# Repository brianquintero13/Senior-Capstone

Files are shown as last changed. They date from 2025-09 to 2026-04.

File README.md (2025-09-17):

# ShadeSync

## Project Description
ShadeSync is an ongoing project aimed at creating a smarter, more convenient way to manage window shades. The idea is to explore how automation and simple technology can improve daily routines, from better sleep at night to easier wake-ups in the morning. Our vision is to design a system that feels natural, reliable, and helpful — one that blends into everyday life and makes it just a little smoother.  

## Technology Stack
Drawing from our project design document, ShadeSync will use a combination of hardware and software to support automation, scheduling, and user interaction:  
- **Microcontroller:** ESP32 (for control, Wi-Fi, and Bluetooth connectivity)  
- **Control Logic:** Scripts to handle shade movement and scheduling routines  
- **Timekeeping:** RTC module or network time sync for reliable scheduling  
- **User Interface:** Android companion app for setup, scheduling, and manual control  
- **Input/Feedback:** Limit switches or encoders for shade positioning, with optional sensors for future features  

## Set Up and Run the Project Locally
This project is still under development, and setup instructions may change as it evolves. In general, the process will include:  
1. Cloning the repository from GitHub.  
2. Opening the project in a development environment.  
3. Uploading the code to the microcontroller or running the app on a device.  
4. Testing and adjusting features as new components are added.  

## Team Members
- Matthew Dauria  
- Brian Quintero  
- Jake Sussner  

**Roles:** Collaborative Development — all team members contribute equally to every part of the project.  

## Unique Contributions
- **Matthew Dauria** – Experience with artificial intelligence, especially in automation, non-playable characters for games, and data tracking.  
- **Brian Quintero** – Background in encrypted equipment, RF signals, PIR sensors, and remote-control systems.  
- **Jake Sussner** – Strong troubleshooting skills in both code and mechanics, with the ability to quickly identify and resolve errors.  

**Note:** While each member brings different skills to the table, we are teaching each other these areas of expertise throughout the project so everyone gains well-rounded knowledge.  

---

*This document will be updated as the project develops.*

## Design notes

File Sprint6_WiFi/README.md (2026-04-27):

## Sprint6 WiFi Firmware Builder Workflow

This firmware supports two profiles:

- `BUILD_PROFILE=1` builder-first mode (seed default WiFi credentials on first boot)
- `BUILD_PROFILE=0` customer mode (no seeded credentials)

### Generate flash-time builder config

From repo root:

```bash
export BUILDER_WIFI_SSID="YourBuilderNetwork"
export BUILDER_WIFI_PASSWORD="YourBuilderPassword"
export DEVICE_SETUP_CODE="YourSetupCode"
./Sprint6_WiFi/tools/generate_builder_config.sh
```

This creates `Sprint6_WiFi/builder_config.local.h` used at compile time.

### Builder handoff checklist

1. Generate builder config header.
2. Flash `Sprint6_WiFi.ino`.
3. Boot device and confirm serial log shows WiFi connected + IP.
4. Verify `GET /health` from builder network.
5. Verify open/close command path.
6. Hand off unit with setup code and reset-button recovery instructions.

### Customer recovery behavior

- Long-press reset button (4+ sec) enters setup AP mode.
- Setup AP has a limited window (default 10 min).
- Provisioning accepts authenticated `POST /wifi-config` only.

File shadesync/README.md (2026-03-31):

This is a [Next.js](https://nextjs.org) project bootstrapped with [`create-next-app`](https://github.com/vercel/next.js/tree/canary/packages/create-next-app).

## Getting Started

First, run the development server:

```bash
npm run dev
# or
yarn dev
# or
pnpm dev
# or
bun dev
```

Open [http://localhost:3000](http://localhost:3000) with your browser to see the result.

You can start editing the page by modifying `app/page.js`. The page auto-updates as you edit the file.

This project uses [`next/font`](https://nextjs.org/docs/app/building-your-application/optimizing/fonts) to automatically optimize and load [Geist](https://vercel.com/font), a new font family for Vercel.

## Arduino Manual Control Wiring

Manual `Open` / `Close` buttons now send commands through the backend to the motor controller over USB serial, and both manual buttons are disabled while the motor is moving.

Set these environment variables in `.env.local`:

```bash
SERIAL_PORT_PATH=/dev/tty.usbserial-0001
SERIAL_BAUD_RATE=115200
MOTOR_COMMAND_TIMEOUT_MS=25000
```

Endpoints used:

- `POST /api/device-command` with `{ "action": "open" }` or `{ "action": "close" }`
- `GET /api/device-status` as Server-Sent Events (`status` events)

Arduino firmware is expected to:

- Accept `OPEN` / `CLOSE` commands via serial (newline-terminated)
- Emit `OPEN complete` / `CLOSE complete` when movement finishes

## Learn More

To learn more about Next.js, take a look at the following resources:

- [Next.js Documentation](https://nextjs.org/docs) - learn about Next.js features and API.
- [Learn Next.js](https://nextjs.org/learn) - an interactive Next.js tutorial.

You can check out [the Next.js GitHub repository](https://github.com/vercel/next.js) - your feedback and contributions are welcome!

## Deploy on Vercel

The easiest way to deploy your Next.js app is to use the [Vercel Platform](https://vercel.com/new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) from the creators of Next.js.

Check out our [Next.js deployment documentation](https://nextjs.org/docs/app/building-your-application/deploying) for more details.

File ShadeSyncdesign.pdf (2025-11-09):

Project Title: ShadeSync

Team Name: The Lightbenders

Team Members:

- Matthew Dauria – Collaborative Development Role
- Jake Sussner – Collaborative Development Role
- Brian Quintero – Collaborative Development Role

(Our team works together across hardware, software, and testing. Each member brings unique strengths but all roles overlap.)

GitHub Repository URL: https://github.com/brianquintero13/Senior-Capstone

Trello Board URL: https://trello.com/b/8fFUBatY/shadesync
Diagrams

Create the required diagrams to help you visualize and communicate the design of your system. Each diagram should be in .png or .jpg format, properly named (e.g., context.png,
dataflow.png), and included in a ZIP file for submission.

### 1. Context diagram

Create a Context Diagram that shows the entire system and its interactions with external entities (users, is clear and shows all important system interactions.

### 2. Data flow diagram

Create a Data Flow Diagram (DFD) showing the flow of data within your system. Choose one of the data and expand it to show how the input becomes output. The diagram should have
sufficient detail and clarity.

### 3. Use case diagram

Create a Use Case Diagram for one of your system’s features.
Include at least five use cases that represent different user interactions with the
system. Clearly define the actors and the use cases that describe how users interact with your system.

### 4. Sequence diagram

Create a Sequence Diagram for one of the use cases from your
Use Case Diagram. This diagram should show the full interactions required for the
selected use case, detailing the messages exchanged between objects

### 5. Class diagram

Create a Class Diagram that shows the classes and methods used in your Sequence Diagram, as well a your system needs. Ensure there are at least four user-defined types represented,
showing the structure of your system’s objects.

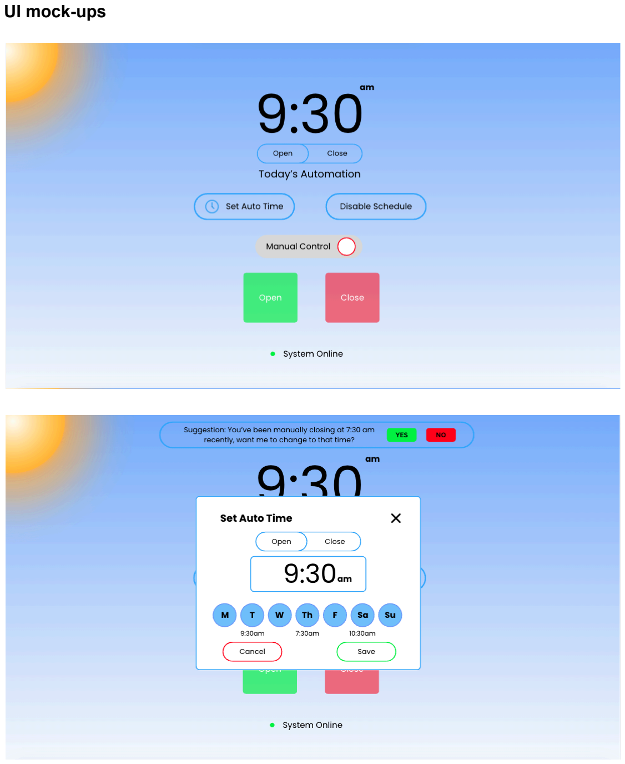
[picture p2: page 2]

UI mock-ups

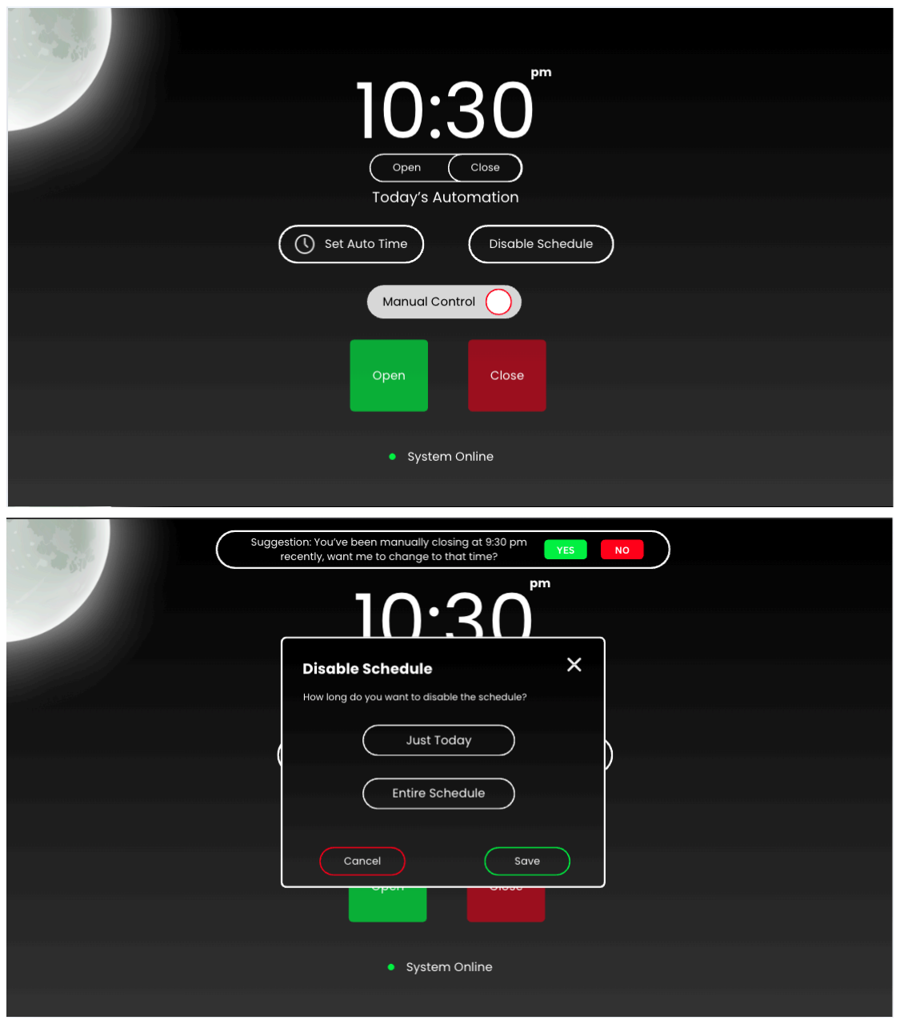
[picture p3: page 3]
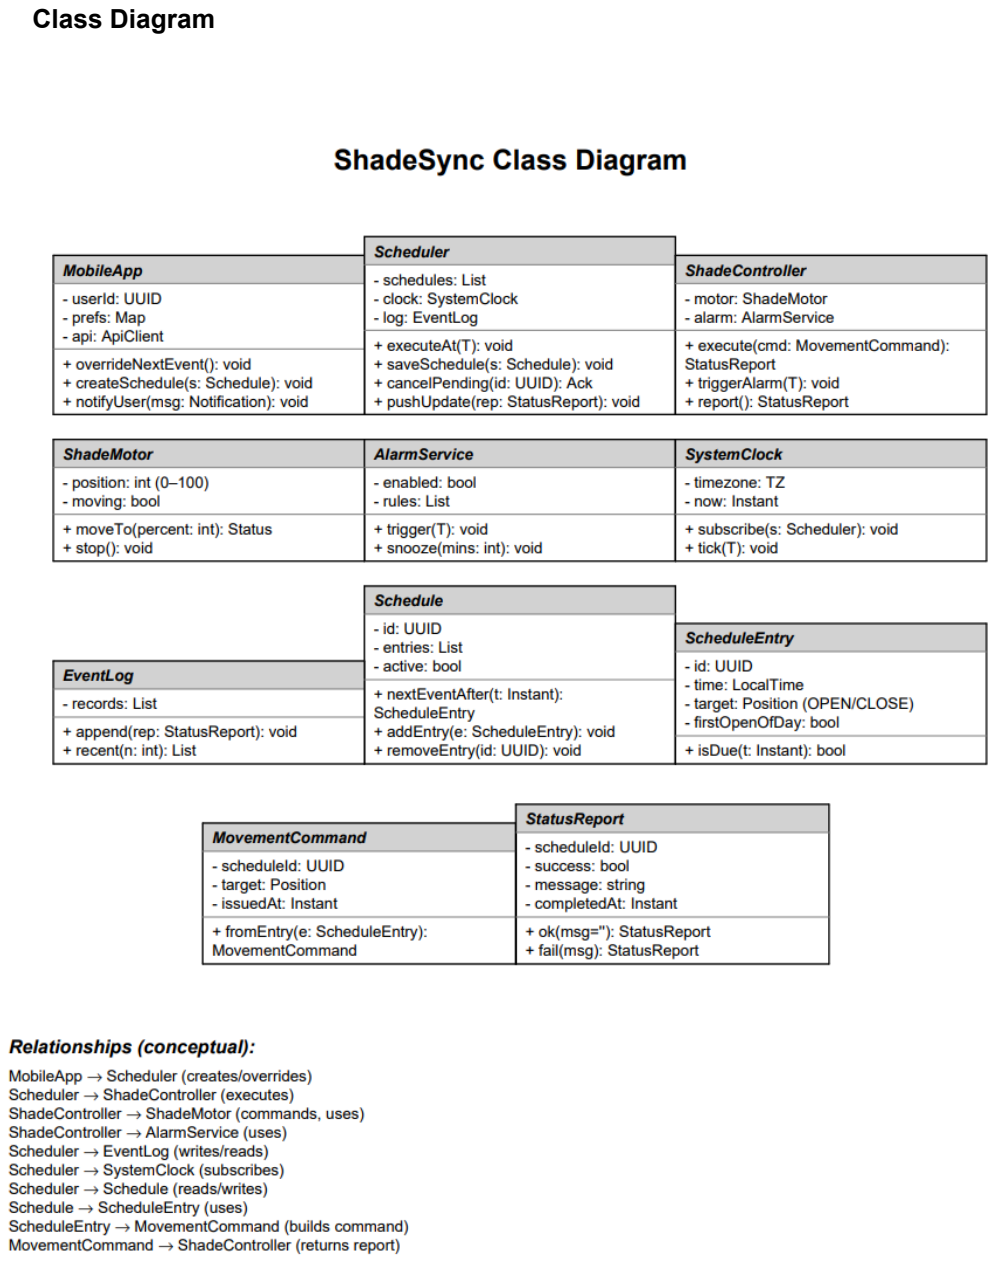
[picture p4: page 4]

Class Diagram

Sequence Diagram

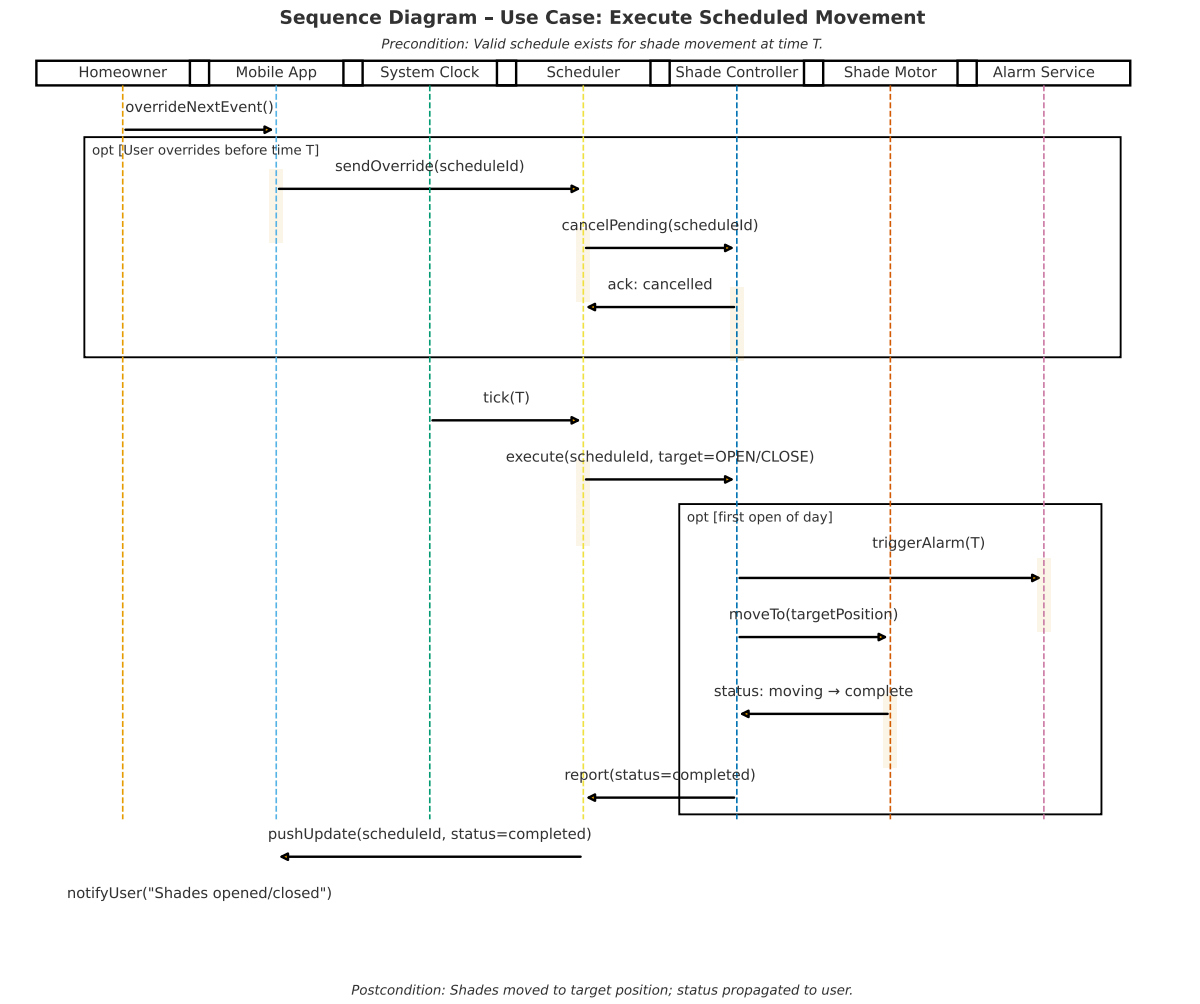
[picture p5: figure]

Use Case Diagram

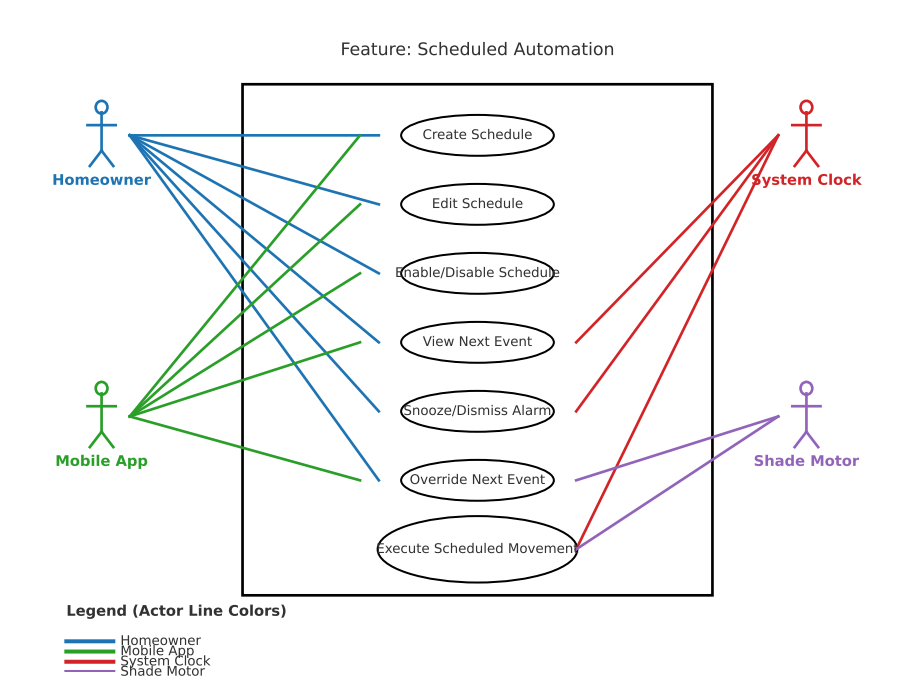
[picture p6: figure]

Data Flow Diagram

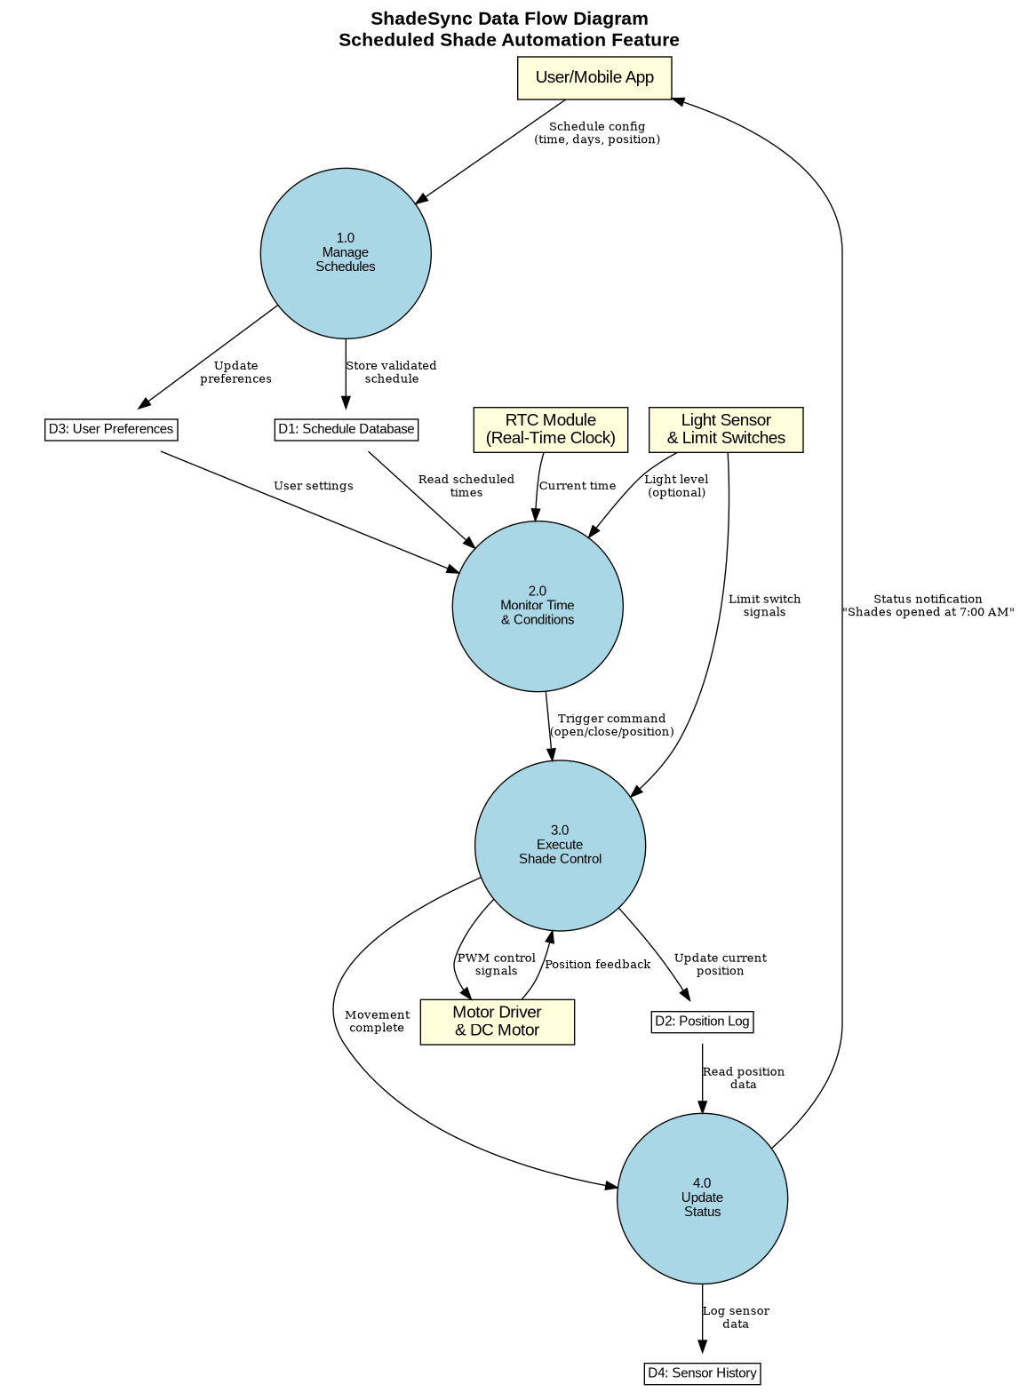
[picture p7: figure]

Context Diagram

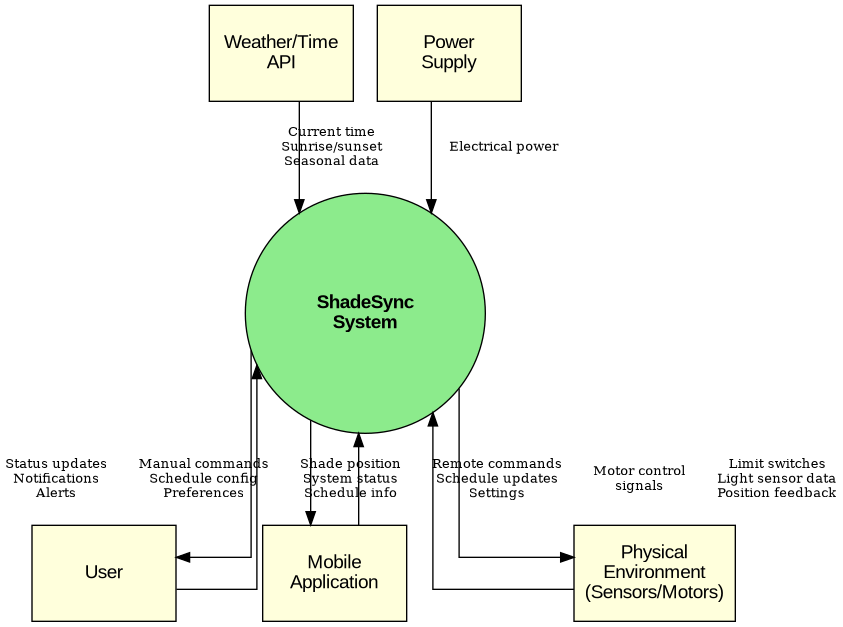
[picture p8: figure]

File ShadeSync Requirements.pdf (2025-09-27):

Project Title: ShadeSync

Team Name: The Lightbenders

Team Members:

- Matthew Dauria – Collaborative Development Role
- Jake Sussner – Collaborative Development Role
- Brian Quintero – Collaborative Development Role

(Our team works together across hardware, software, and testing. Each member brings unique strengths but all roles overlap.)

GitHub Repository URL: https://github.com/brianquintero13/Senior-Capstone

Trello Board URL: https://trello.com/b/8fFUBatY/shadesync

Brief Summary

ShadeSync is a smart motorized window shade system designed to improve comfort, efficiency, and daily routines. It provides scheduled automation, manual override through physical controls or a remote, and mobile connectivity for convenience. Beyond light control, the system can help regulate indoor temperature by lowering shades when no one is home, reducing energy use. Planned AI features will further adapt schedules to user habits and seasonal changes, creating a reliable and customizable solution for modern living.

Main Features

1. Scheduled Shade Automation
Shades open and close at set times, supporting healthier routines and improving energy efficiency by reducing heat gain or loss when the home is unoccupied.
2. Mobile Application Integration
A companion app allows users to remotely control shades, manage schedules, and customize preferences for greater convenience and flexibility.
3. Adaptive Intelligence (Planned)
Future integration of machine learning will analyze user behavior and seasonal light patterns to recommend optimized schedules, creating a more adaptive system.

Sprint Outline

Sprint 1: Focus on foundational tasks by defining the hardware requirements, selecting components, mounting the shades, and enabling manual control with safety stops.

Sprint 2: Assemble and debug the prototype, implement a reliable timekeeping system, and introduce scheduled automation for morning opening and night closing, with the alarm feature as a secondary goal.

Sprint 3: Finalize the system by connecting the prototype to mounted shades, integrating mobile app control, and adding in-app schedule management, followed by testing for consistency and stability.

MOSCOW Summary:

- Must Have: Hardware setup, safety measures, automated scheduling
- Should Have: Mobile app control, alarm function
- Could Have: AI suggestions, customization options, environmental sensor
- Won’t Have: Alternative shade types, full cross-platform app deployment

Extra Work (If Time Allows)

- Cross-Platform App: Expand beyond Android to develop a full iOS/Android mobile application.
- Alternative Shade Types: Extend functionality to support shades that open left-to-right as well as top-down.
- AI Behavior Suggestions: Implement behavior tracking to recommend optimized schedules based on user habits and seasonal changes.
- Accessibility & Customization: Add optional features such as LED indicators, customizable alarm sounds, and mobile notifications.
- Sunlight Auto-Adjust: Integrate a light sensor to dynamically adjust shades according to user-defined brightness preferences.

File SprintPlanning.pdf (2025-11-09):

# ShadeSync

## The Lightbenders

Brian Quintero, Matthew Dauria, Jake Sussner

GitHub repository: https://github.com/brianquintero13/Senior-Capstone

Trello board: https://trello.com/b/8fFUBatY/shadesync

## Sprint 1

Spring Goal: Defining the hardware requirements, selecting components, mounting the shades, and enabling manual control with safety stops.

Tasks:
1. Define ShadeSync’s hardware and requirements, to select the correct components before building.
a. Effort: ~1-2 hours
b. Assigned Team Member: Matthew Dauria
2. Properly hang up shades, so the system can open and close them.
a. Effort: ~1 hour
b. Assigned Team Member: Brian Quintero
c. Dependency: Task 1 needs to be completed
3. Open and close the shades manually, so I can control the amount of light in my room.
a. Effort: ~1 hour
b. Assigned Team Member: Jake Sussner
c. Dependency: Task 2 needs to be completed

## Sprint 2

Spring Goal: Assemble and debug the prototype, implement a reliable timekeeping system, and introduce scheduled automation for morning opening and night closing, with the alarm feature as a secondary goal.

Tasks:
1. Build a working prototype, so we can test hardware, software, and communication together.
a. Effort: ~1-3 days
b. Assigned Team Member(s): All
2. Make shades automatically open/close, so my routine happens without manual effort.

a. Effort: ~3-5 days
b. Assigned Team Member(s): All
c. Dependency: Task 1 needs to be completed with the mobilized frame in hand
3. Stop shades automatically so they don’t get damaged.
a. Effort: ~3 hours
b. Assigned Team Member: All Members
c. Dependency: Task 2 needs to be completed

## Sprint 3

Sprint Goal: Deploy ShadeSync on the mounted window frame and demonstrate end-to-end control from a phone (manual + scheduled), while enabling basic behavior-based recommendations that adapt schedules over time.

## Trello board

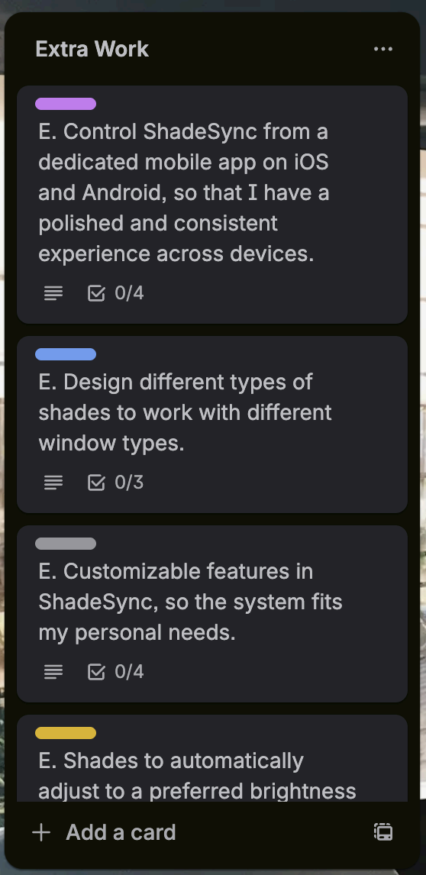
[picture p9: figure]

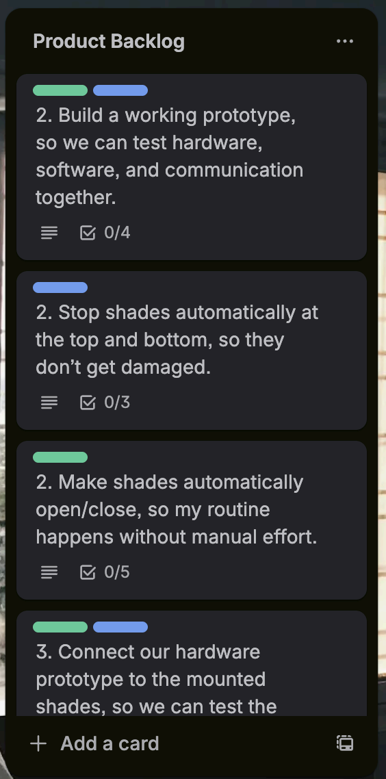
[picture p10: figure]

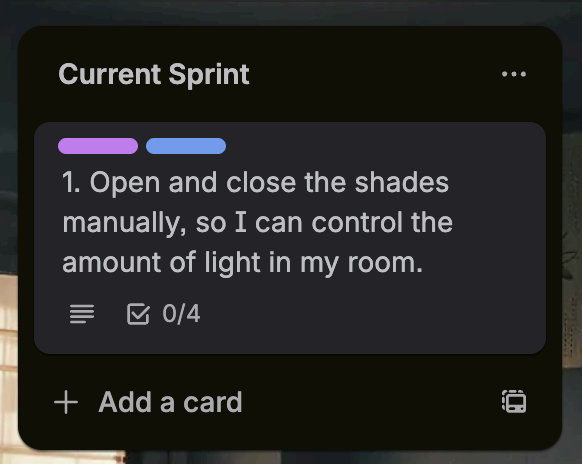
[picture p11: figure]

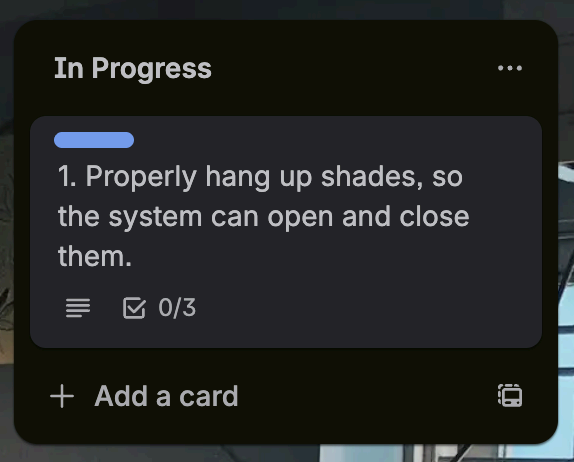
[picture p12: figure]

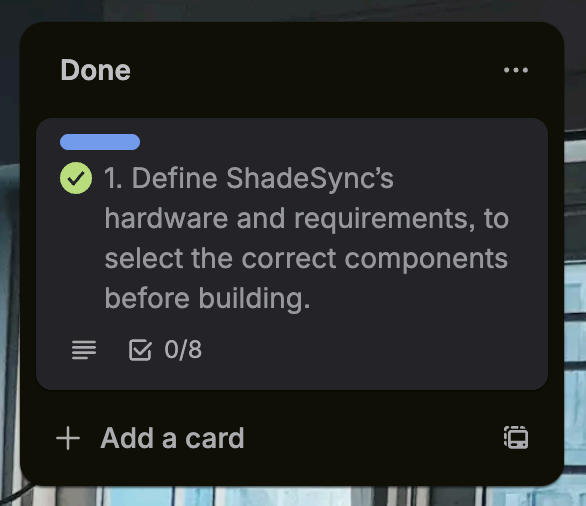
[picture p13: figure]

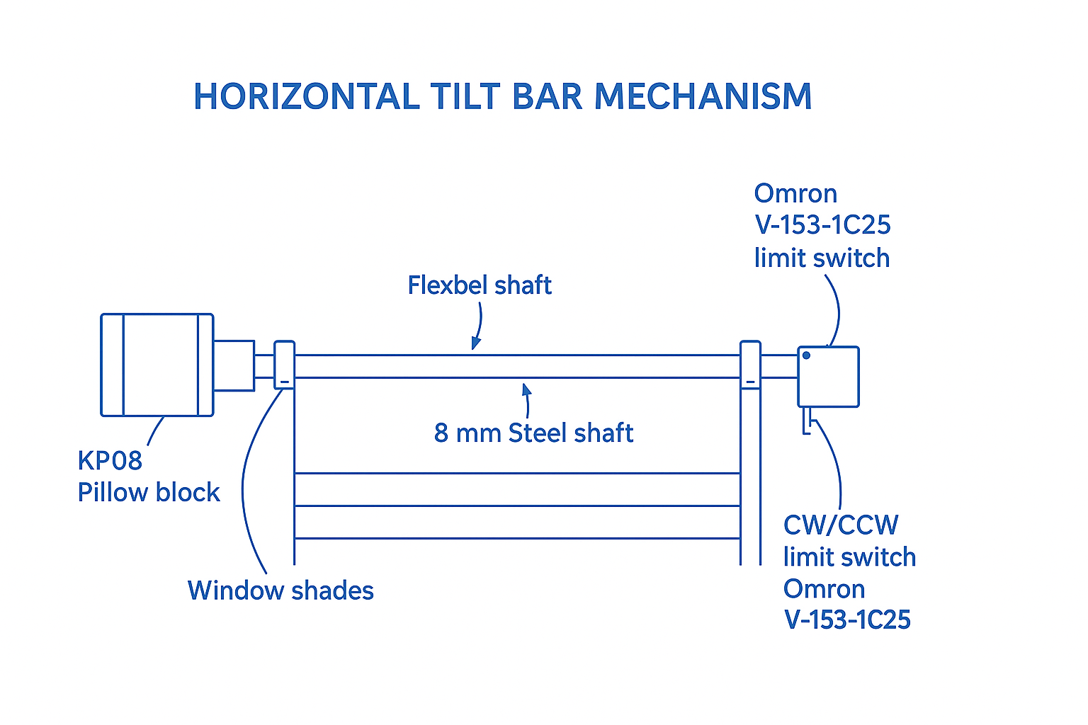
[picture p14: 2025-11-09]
Shade Design Blueprint.png

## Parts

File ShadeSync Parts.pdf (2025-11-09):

# ShadeSync — Budget-Fit Bill of Materials (BOM)

Totals are ballpark and vary slightly by seller.

### Totals Summary

Section | Subtotal
Shared base (reuse for all) | $187.01
Add vertical (5 rollers) | $200.10
Add horizontal tilt | $62.29
Shared + Vertical | $387.11
Shared + Horizontal | $249.30
Shared + Vertical + Horizontal | $449.40

### Shared base (buy once, reused for both builds)

Item | Qty | Unit | Ext. | Notes / Purpose
BIGTREETECH SKR 1.4 (control board) (https://www.zyltech.com/electronics-motors-more/official-bigtree-tech-skr/) (Zyltech) | 1 | $24.95 | $24.95 | Main controller for up to 5 steppers; STEP/DIR outputs, endstops, 24 V input.
TMC2209 stepper drivers (5-pack) (https://wuxn3d.com/products/bigtreetech-tmc2209-stepper-driver) (Wuxn3D) | 1 | $29.99 | $29.99 | Silent, reliable drivers; one per motor axis (x5).
ESP32 DevKitC (Wi-Fi/BLE) (https://www.digikey.com/en/products/detail/espressif-systems/ESP32-DEVKITC-32E/12091810) (Digi-Key) | 1 | $10.00 | $10.00 | Mobile app + weather logic; sends commands to

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
). Mean Well LRS-200-24 (24 V PSU) (Mouser) | 1 | $23.30 | $23.30 | Clean 24 V power for motors and drivers. Pololu D36V28F5 (5 V buck, 3.2 A) (Pololu) | 1 | $21.95 | $21.95 | Steps 24 V down to 5 V fo

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
s. 22 mm latching Emergency Stop (1NO/1NC) (Amazon) | 1 | $13.99 | $13.99 | Safety cu

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
U. WAGO 221-413 Lever Nuts (3-conductor, 50-pack) (Amazon) | 1 | $19.84 | $19.84 | Safe, too

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
s. 18 AWG silicone wire kit (multi-color) (Amazon) | 1 | $18.00 | $18.00 | Power wi

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
d. JST-XH connector kit / pre-crimp leads (Amazon) | 1 | $9.99 | $9.99 | Connect motors, endstops, an

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
y. Hammond 1591 enclosure (size to fit) (Amazon) | 1 | $15.00 | $15.00 | Mount

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
fe. Section subtotal: $187.01

### Build A — 5 independent vertical rollers (add to shared base)

Item (clickable) Qty | Unit | Ext. | Notes / Purpose

NEMA-17
stepper
17HS19-1684S
1 (45 N·cm) (https://www.omc-stepperonline.com/nema-17-bipolar-1-8deg-45ncm-64oz-in-1-68a-2-8v-42x42x48mm-4-wires-17hs19-1684s1)
(StepperOnline)
5 | $10.44 | $52.20 | One motor per roller lane.

6061-T6
aluminum tube,
1" OD x 0.058"
wall (36") (https://www.onlinemetals.com/en/buy/aluminum/1-od-x-0-058-wall-x-0-884-id-aluminum-round-tube-6061-t6-drawn/pid/4342)
(OnlineMetals)
2 | $28.95 | $57.90 | Cut into five roller cores; deburr ends.

608ZZ bearings
(10-pack) (https://www.amazon.com/Bearings-Double-Shielded-Miniature-Skateboard/dp/B07H83VV6B)
(Amazon)
1 | $10.00 | $10.00 | Two bearings per roller for smooth support.

Flexible shaft
couplers 5 mm
-> 5 mm
(5-pack) (https://www.amazon.com/Saiper-Couplings-Connector-Compatible-Accessories/dp/B07M5Q7HTV)
(Amazon)
1 | $15.00 | $15.00 | Couple motor shafts to roller hub inserts.

NEMA-17
L-brackets
(5-pack) (https://www.amazon.com/5pcs-Mounting-Bracket-Mount-Stepper-Motor/dp/B07YY6WH1D)
(Amazon)
1 | $18.00 | $18.00 | Rigid mounting of motors to the wooden frame.

Omron
V-153-1C25
long-lever limit
switch (https://www.mouser.com/ProductDetail/Omron-Electronics/V-153-1C25?qs=WOBxwZpV8jWr%252BiSFeM5Nxw%3D%3D)
(Mouser)
10 | $4.70 | $47.00 | Top/bottom endstops for each lane (2 per roller).

Section subtotal: $200.10

### Build B — Horizontal tilt bar (add to shared base)

Item (clickable) Qty | Unit | Ext. | Notes / Purpose

NEMA-17
stepper
17HS19-1684S
1 (45 N·cm) (https://www.omc-stepperonline.com/nema-17-bipolar-1-8deg-45ncm-64oz-in-1-68a-2-8v-42x42x48mm-4-wires-17hs19-1684s1)
(StepperOnline)
1 | $10.44 | $10.44 | Drives the common tilt shaft.

8 mm linear
steel shaft
(~400 mm) (https://www.amazon.com/uxcell-Linear-Hardened-Printer-Machine/dp/B0D2BJ15MY)
(Amazon)
1 | $20.49 | $20.49 | Common tilt bar across slats.

KP08 pillow
blocks (8 mm,
pair) (https://www.amazon.com/uxcell-Mounted-Pillow-Insert-Bearing/dp/B073LDH4L7) (Amazon)
1 | $12.00 | $12.00 | Shaft supports at ends; keeps alignment.

Flexible shaft
coupler 5 mm
-> 8 mm (https://www.amazon.com/Befenybay-Flexible-Coupling-Diameter-Aluminum/dp/B0843TFVWZ)
(Amazon)
1 | $8.00 | $8.00 | Couple motor (5 mm) to 8 mm tilt shaft.

Omron
V-153-1C25
long-lever limit
switch (https://www.mouser.com/ProductDetail/Omron-Electronics/V-153-1C25?qs=WOBxwZpV8jWr%252BiSFeM5Nxw%3D%3D)
(Mouser)
2 | $5.68 | $11.36 | CW/CCW tilt endstops (2 total).

Section subtotal: $62.29

### Connection Overview (how the parts are used)

- AC mains -> Emergency-stop (series on hot) -> Mean Well LRS-200-24 PSU -> 24 V to SKR and TMC2209 drivers.
- PSU -> Pololu 5 V buck -> ESP32 5 V and any sensors.
- ESP32 communicates with SKR (UART or STEP/DIR GPIO) and hosts the mobile/HTTP API + weather logic.
- Vertical build: each lane uses 1x NEMA-17, a 5->5 mm coupler to a 1" aluminum roller, with 608ZZ bearings and two limit switches (top/bottom).
- Horizontal build: one NEMA-17 -> 5->8 mm coupler -> 8 mm shaft on KP08 pillow blocks; two limit switches (CW/CCW).

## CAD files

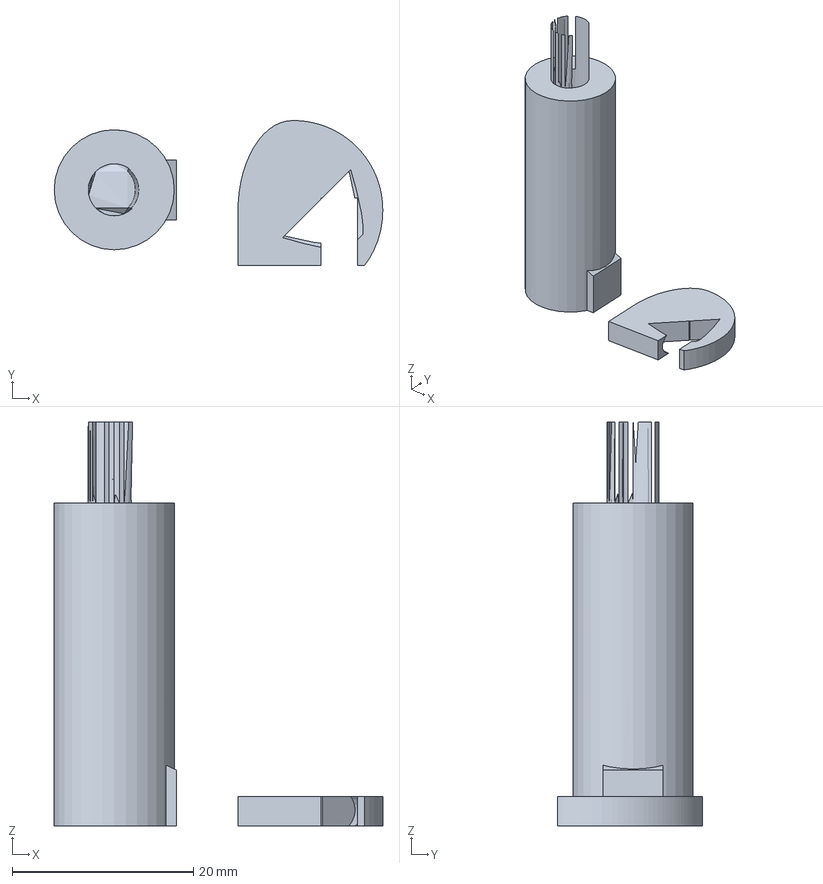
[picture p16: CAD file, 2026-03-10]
blindhook.3mf
36.3 x 16.0 x 44.6 mm

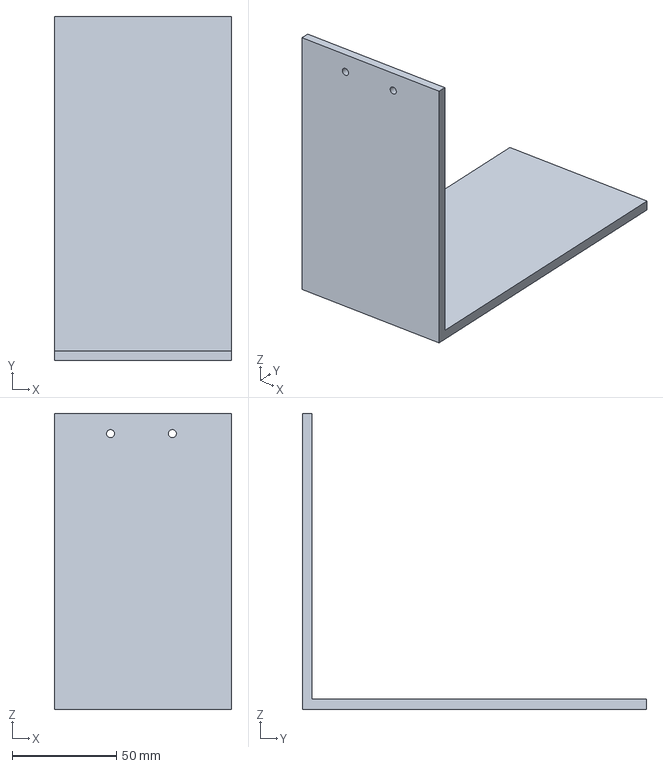
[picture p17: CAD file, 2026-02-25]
MotorClamp.3mf
85.0 x 165.0 x 142.0 mm

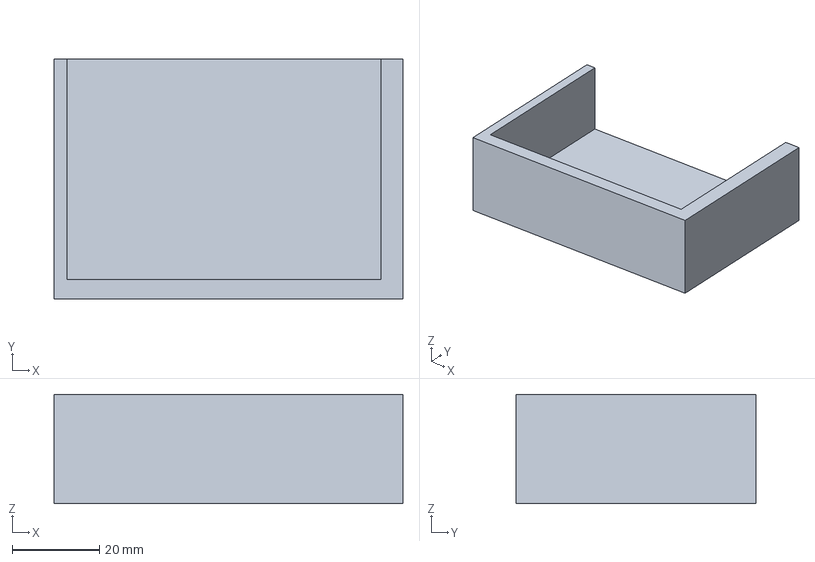
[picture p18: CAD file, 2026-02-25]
MotorHolder.3mf
80.0 x 55.0 x 25.0 mm

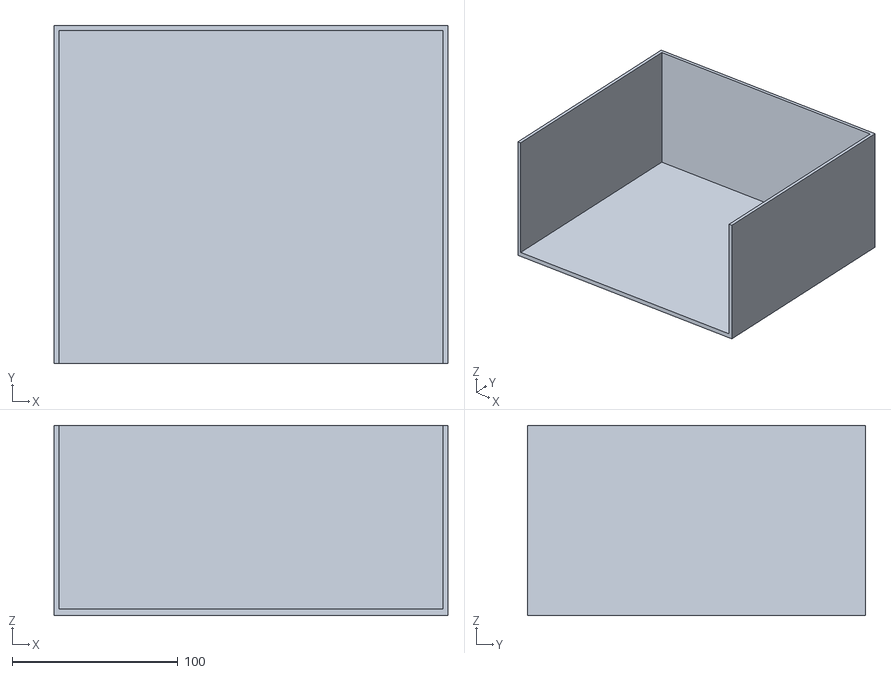
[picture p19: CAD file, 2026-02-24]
EndBoxPiece.stl
238.0 x 204.0 x 115.0

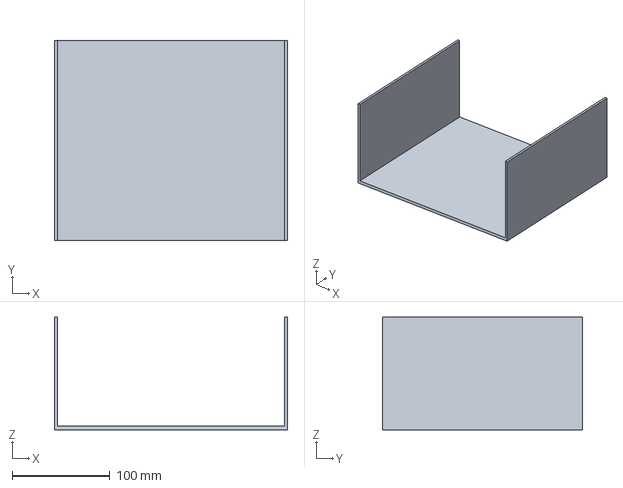
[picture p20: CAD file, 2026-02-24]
MiddleBoxPiece.3mf
238.0 x 204.0 x 115.0 mm

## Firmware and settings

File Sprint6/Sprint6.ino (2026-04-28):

#include <WiFi.h>
#include <WiFiServer.h>
#include <EEPROM.h>

// Pin definitions
#define STEP_PIN 12
#define DIR_PIN 14
#define ENABLE_PIN 13

// EEPROM settings
#define EEPROM_SIZE 512
#define SSID_ADDR 0
#define PASSWORD_ADDR 100

// Motor settings
const int stepsPerRevolution = 1600;
const int rotations = 5;
const int totalSteps = stepsPerRevolution * rotations;

// Command settings
const int OPEN_DIR = HIGH;
const int CLOSE_DIR = LOW;

// WiFi settings
char ssid[50] = "";
char password[50] = "";

WiFiServer server(80);

// Motor state
bool isMoving = false;

// Function to save WiFi credentials to EEPROM
void saveWiFiCredentials(const char* newSSID, const char* newPassword) {
  EEPROM.begin(EEPROM_SIZE);
  
  // Save SSID
  for (int i = 0; i < 50; i++) {
    EEPROM.write(SSID_ADDR + i, newSSID[i]);
    if (newSSID[i] == '\0') break;
  }
  
  // Save password
  for (int i = 0; i < 50; i++) {
    EEPROM.write(PASSWORD_ADDR + i, newPassword[i]);
    if (newPassword[i] == '\0') break;
  }
  
  EEPROM.commit();
  EEPROM.end();
  Serial.println("WiFi credentials saved to EEPROM");
}

// Function to load WiFi credentials from EEPROM
void loadWiFiCredentials() {
  EEPROM.begin(EEPROM_SIZE);
  
  // Load SSID
  for (int i = 0; i < 50; i++) {
    ssid[i] = EEPROM.read(SSID_ADDR + i);
    if (ssid[i] == '\0') break;
  }
  
  // Load password
  for (int i = 0; i < 50; i++) {
    password[i] = EEPROM.read(PASSWORD_ADDR + i);
    if (password[i] == '\0') break;
  }
  
  EEPROM.end();
  Serial.print("Loaded SSID: ");
  Serial.println(ssid);
  Serial.println("Password loaded (hidden)");
}

// Function to check if credentials exist in EEPROM
bool hasStoredCredentials() {
  EEPROM.begin(EEPROM_SIZE);
  char firstChar = EEPROM.read(SSID_ADDR);
  EEPROM.end();
  return (firstChar != 0 && firstChar != 255);
}

// Function to clear WiFi credentials from EEPROM
void clearWiFiCredentials() {
  EEPROM.begin(EEPROM_SIZE);
  
  // Clear SSID
  for (int i = 0; i < 50; i++) {
    EEPROM.write(SSID_ADDR + i, 0);
  }
  
  // Clear password
  for (int i = 0; i < 50; i++) {
    EEPROM.write(PASSWORD_ADDR + i, 0);
  }
  
  EEPROM.commit();
  EEPROM.end();
  Serial.println("WiFi credentials cleared from EEPROM");
}

// Function to decode URL-encoded strings
String urlDecode(String input) {
  String output = "";
  for (int i = 0; i < input.length(); i++) {
    char c = input.charAt(i);
    if (c == '+') {
      output += ' ';
    } else if (c == '%') {
      if (i + 2 < input.length()) {
        String hex = input.substring(i + 1, i + 3);
        char decoded = (char)strtol(hex.c_str(), NULL, 16);
        output += decoded;
        i += 2;
      }
    } else {
      output += c;
    }
  }
  return output;
}

void rotateMotor(int direction) {
  isMoving = true;
  digitalWrite(DIR_PIN, direction);

  for (int i = 0; i < totalSteps; i++) {
    digitalWrite(STEP_PIN, HIGH);
    delayMicroseconds(800);
    digitalWrite(STEP_PIN, LOW);
    delayMicroseconds(800);
  }
  isMoving = false;
}

void setup() {
  Serial.begin(115200);
  
  // Add delay to allow Serial Monitor to connect
  delay(2000);
  
  Serial.println("=================================");
  Serial.println("ESP32 Starting Up...");
  Serial.println("=================================");
  
  // Check if BOOT button is pressed to clear EEPROM
  pinMode(0, INPUT_PULLUP);
  delay(100);
  if (digitalRead(0) == LOW) {
    Serial.println("BOOT button pressed - clearing WiFi credentials from EEPROM");
    clearWiFiCredentials();
    Serial.println("EEPROM cleared. Release BOOT button and restart to configure new WiFi.");
    while (digitalRead(0) == LOW) {
      delay(100);
    }
    ESP.restart();
  }
  
  // Motor pins
  pinMode(STEP_PIN, OUTPUT);
  pinMode(DIR_PIN, OUTPUT);
  pinMode(ENABLE_PIN, OUTPUT);
  digitalWrite(ENABLE_PIN, LOW); // Enable motor driver
  
  Serial.println("Motor pins configured");

  // Load WiFi credentials from EEPROM
  if (hasStoredCredentials()) {
    Serial.println("Found stored WiFi credentials");
    loadWiFiCredentials();
    
    // Validate SSID is not empty
    if (strlen(ssid) == 0 || ssid[0] == 0 || ssid[0] == 255) {
      Serial.println("Invalid SSID in EEPROM, clearing and starting AP mode");
      clearWiFiCredentials();
      WiFi.mode(WIFI_AP);
      WiFi.softAP("ShadeSync-Setup", "setup1234");
      Serial.println("AP mode started");
      Serial.print("AP IP: ");
      Serial.println(WiFi.softAPIP());
      server.begin();
      Serial.println("Server started in AP mode");
      Serial.println("Connect to 'ShadeSync-Setup' WiFi and configure your network");
      Serial.println("=================================");
      return;
    }
  } else {
    Serial.println("No stored WiFi credentials found");
    Serial.println("Please configure WiFi via the web interface");
    // Start in AP mode for initial configuration
    WiFi.mode(WIFI_AP);
    WiFi.softAP("ShadeSync-Setup", "setup1234");
    Serial.println("AP mode started");
    Serial.print("AP IP: ");
    Serial.println(WiFi.softAPIP());
    server.begin();
    Serial.println("Server started in AP mode");
    Serial.println("Connect to 'ShadeSync-Setup' WiFi and configure your network");
    Serial.println("=================================");
    return; // Skip WiFi connection in STA mode
  }

  // WiFi setup
  Serial.println("Connecting to WiFi...");
  Serial.print("SSID: ");
  Serial.println(ssid);
  
  // Set WiFi mode
  WiFi.mode(WIFI_STA);
  WiFi.disconnect();
  delay(100);
  
  // Try multiple connection attempts
  int attempts = 0;
  bool connected = false;
  
  while (!connected && attempts < 40) {
    Serial.print("Attempt ");
    Serial.print(attempts + 1);
    Serial.print(" - ");
    
    WiFi.begin(ssid, password);
    
    // Wait for connection with timeout
    int connectionAttempts = 0;
    while (WiFi.status() != WL_CONNECTED && connectionAttempts < 20) {
      delay(500);
      connectionAttempts++;
      
      if (WiFi.status() == WL_CONNECTED) {
        connected = true;
        break;
      }
    }
    
    if (connected) {
      break;
    }
    
    Serial.print("Status: ");
    Serial.println(WiFi.status());
    
    // Reset and try different approach
    WiFi.disconnect();
    delay(1000);
    
    // Every 10 attempts, try with WiFi power cycle
    if (attempts % 10 == 9) {
      Serial.println("Power cycling WiFi...");
      WiFi.mode(WIFI_OFF);
      delay(1000);
      WiFi.mode(WIFI_STA);
      delay(500);
    }
    
    attempts++;
  }
  
  if (WiFi.status() == WL_CONNECTED) {
    Serial.println("WiFi connected!");
    Serial.print("IP address: ");
    Serial.println(WiFi.localIP());
    
    server.begin();
    Serial.println("Server started");
    Serial.println("=================================");
  } else {
    Serial.println("Failed to connect to WiFi after all attempts");
    Serial.println("Clearing credentials and starting AP mode for reconfiguration");
    clearWiFiCredentials();
    
    // Start in AP mode for reconfiguration
    WiFi.mode(WIFI_AP);
    WiFi.softAP("ShadeSync-Setup", "setup1234");
    Serial.println("AP mode started");
    Serial.print("AP IP: ");
    Serial.println(WiFi.softAPIP());
    server.begin();
    Serial.println("Server started in AP mode");
    Serial.println("Connect to 'ShadeSync-Setup' WiFi and configure your network");
    Serial.println("=================================");
  }
}

void loop() {
  // Only check WiFi connection if we're in STA mode (not AP mode)
  if (WiFi.getMode() == WIFI_STA && WiFi.status() != WL_CONNECTED) {
    Serial.println("WiFi disconnected, attempting to reconnect...");
    WiFi.disconnect();
    delay(1000);
    WiFi.begin(ssid, password);
    
    int reconnectAttempts = 0;
    while (WiFi.status() != WL_CONNECTED && reconnectAttempts < 20) {
      delay(500);
      Serial.print(".");
      reconnectAttempts++;
    }
    
    if (WiFi.status() == WL_CONNECTED) {
      Serial.println("\nWiFi reconnected!");
      Serial.print("IP address: ");
      Serial.println(WiFi.localIP());
      server.begin();
      Serial.println("Server restarted");
    } else {
      Serial.println("\nFailed to reconnect to WiFi");
    }
  }
  
  WiFiClient client = server.available();
  
  if (client) {
    Serial.println("Client connected");
    String currentLine = "";
    String request = "";
    
    // Read the request
    while (client.connected()) {
      if (client.available()) {
        char c = client.read();
        request += c;
        
        if (c == '\n') {
          if (currentLine.length() == 0) {
            // End of headers, send response
            break;
          } else {
            currentLine = "";
          }
        } else if (c != '\r') {
          currentLine += c;
        }
      }
    }
    
    // Process the request
    Serial.print("Request: ");
    Serial.println(request);
    
    // Send HTTP response
    client.println("HTTP/1.1 200 OK");
    client.println("Content-Type: text/plain");
    client.println("Access-Control-Allow-Origin: *");
    client.println("Access-Control-Allow-Methods: GET, POST, OPTIONS");
    client.println("Access-Control-Allow-Headers: Content-Type");
    client.println("Connection: close");
    client.println();
    
    // Check for commands in the request
    if (request.indexOf("GET / ") != -1 || request.indexOf("GET /index.html") != -1) {
      // Root path - return simple response
      client.print("ShadeSync ESP32 is running in AP mode. Please configure WiFi via your website.");
    } else if (request.indexOf("GET /OPEN") != -1) {
      if (!isMoving) {
        Serial.println("Received OPEN command");
        rotateMotor(OPEN_DIR);
        client.print("OPEN complete");
      } else {
        client.print("BUSY");
      }
    } else if (request.indexOf("GET /CLOSE") != -1) {
      if (!isMoving) {
        Serial.println("Received CLOSE command");
        rotateMotor(CLOSE_DIR);
        client.print("CLOSE complete");
      } else {
        client.print("BUSY");
      }
    } else if (request.indexOf("GET /WIFI_CONFIG") != -1) {
      // Parse SSID and password from request
      int ssidStart = request.indexOf("ssid=") + 5;
      int ssidEnd = request.indexOf("&", ssidStart);
      if (ssidEnd == -1) ssidEnd = request.indexOf(" ", ssidStart);
      
      int passwordStart = request.indexOf("password=") + 9;
      int passwordEnd = request.indexOf(" ", passwordStart);
      if (passwordEnd == -1) passwordEnd = request.length();
      
      String newSSID = request.substring(ssidStart, ssidEnd);
      String newPassword = request.substring(passwordStart, passwordEnd);
      
      // Decode URL encoding (handles %20 for spaces, etc.)
      newSSID = urlDecode(newSSID);
      newPassword = urlDecode(newPassword);
      
      Serial.println("Received WiFi credentials:");
      Serial.print("SSID: ");
      Serial.println(newSSID);
      
      // Save to EEPROM
      saveWiFiCredentials(newSSID.c_str(), newPassword.c_str());
      
      // Update current credentials
      newSSID.toCharArray(ssid, 50);
      newPassword.toCharArray(password, 50);
      
      client.print("WiFi credentials saved. Rebooting...");
      Serial.println("Rebooting ESP32 to apply new WiFi settings...");
      delay(1000);
      ESP.restart();
    } else if (request.indexOf("GET /CLEAR_WIFI") != -1) {
      // Clear WiFi credentials and reboot into AP mode
      clearWiFiCredentials();
      client.print("WiFi credentials cleared. Rebooting into AP mode...");
      Serial.println("Rebooting ESP32 into AP mode for reconfiguration...");
      delay(1000);
      ESP.restart();
    } else {
      client.print("Unknown command");
    }
    
    client.stop();
    Serial.println("Client disconnected");
  }
}

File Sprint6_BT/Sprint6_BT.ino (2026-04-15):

/*
  Sprint6_BT.ino
  Separate firmware for ESP32 motor control over:
  1) USB Serial (for local debugging)
  2) Bluetooth Classic SPP (for wireless command transport)

  Expected commands:
    OPEN
    CLOSE

  Expected responses:
    OPEN complete
    CLOSE complete
    BUSY
    Unknown command. Use OPEN or CLOSE.
*/

#include "BluetoothSerial.h"

// Pin definitions
#define STEP_PIN 12
#define DIR_PIN 14
#define ENABLE_PIN 13

// Motor settings
const int stepsPerRevolution = 1600;
const int rotations = 5;
const int totalSteps = stepsPerRevolution * rotations;

// Command settings
const int OPEN_DIR = HIGH;
const int CLOSE_DIR = LOW;

// Bluetooth settings
const char *BT_DEVICE_NAME = "ShadeSync-ESP32";

BluetoothSerial SerialBT;
bool isMoving = false;

void rotateMotor(int direction) {
  isMoving = true;
  digitalWrite(DIR_PIN, direction);

  for (int i = 0; i < totalSteps; i++) {
    digitalWrite(STEP_PIN, HIGH);
    delayMicroseconds(800);
    digitalWrite(STEP_PIN, LOW);
    delayMicroseconds(800);
  }

  isMoving = false;
}

void handleCommand(String cmd, Stream &replyPort) {
  cmd.trim();
  cmd.toUpperCase();

  if (cmd.length() == 0) {
    return;
  }

  if (isMoving) {
    replyPort.println("BUSY");
    return;
  }

  if (cmd == "OPEN") {
    rotateMotor(OPEN_DIR);
    replyPort.println("OPEN complete");
    return;
  }

  if (cmd == "CLOSE") {
    rotateMotor(CLOSE_DIR);
    replyPort.println("CLOSE complete");
    return;
  }

  replyPort.println("Unknown command. Use OPEN or CLOSE.");
}

void setup() {
  pinMode(STEP_PIN, OUTPUT);
  pinMode(DIR_PIN, OUTPUT);
  pinMode(ENABLE_PIN, OUTPUT);
  digitalWrite(ENABLE_PIN, LOW); // Enable motor driver

  Serial.begin(115200);
  delay(300);

  if (!SerialBT.begin(BT_DEVICE_NAME)) {
    Serial.println("Bluetooth start failed");
  } else {
    Serial.print("Bluetooth ready. Device name: ");
    Serial.println(BT_DEVICE_NAME);
  }

  Serial.println("Ready. Send OPEN or CLOSE via USB serial or Bluetooth SPP.");
}

void loop() {
  if (Serial.available() > 0) {
    String usbCmd = Serial.readStringUntil('\n');
    handleCommand(usbCmd, Serial);
  }

  if (SerialBT.available() > 0) {
    String btCmd = SerialBT.readStringUntil('\n');
    handleCommand(btCmd, SerialBT);

    // Mirror command activity to USB serial for debugging visibility.
    btCmd.trim();
    if (btCmd.length() > 0) {
      Serial.print("BT command received: ");
      Serial.println(btCmd);
    }
  }
}

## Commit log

2025-11-09 Added Spring Planning file
2025-11-12 FEAT - Made a simple landing page and login/signup page
2025-11-28 FEAT - The toggle buttons now work
2025-12-05 Added a darker background for the close toggle switch
2025-12-10 Fixed manual toggle, open and close buttons now work when toggle is on
2026-02-08 Added images of shadesync hardware wiring configurations
2026-02-24 Added 3D print files
    [EndBoxPiece.stl, MiddleBoxPiece.3mf, blindhook.3mf]
2026-02-25 Added 3D models
    [MotorClamp.3mf, MotorHolder.3mf, blindhook.3mf]
2026-03-10 Blind hook 3d print file
    [blindhook.3mf]
2026-03-31 [UPDATE]
    wired web version buttons work
2026-04-20 FEAT - Made many changes
    - Tested all edge cases of opening and closing
    - Added toasts for all shade operations
    - Schedule is cached for faster run time
    - UI updates (wider buttons, got rid of open/close toggle)
    - added a manual entries counter
2026-04-21 [UPDATE]
    Fixed Centering
    Adjusted AI energy saving tips
    Have setup/ready for arduino to auto connect to the wifi setup in the user settings. Need to upload the arduino code to the arduino, then we should be set?
    [Sprint6_WiFi.ino]
2026-04-28 added test email button
